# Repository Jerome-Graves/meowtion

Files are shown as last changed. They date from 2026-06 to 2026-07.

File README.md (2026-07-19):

<p align="center">
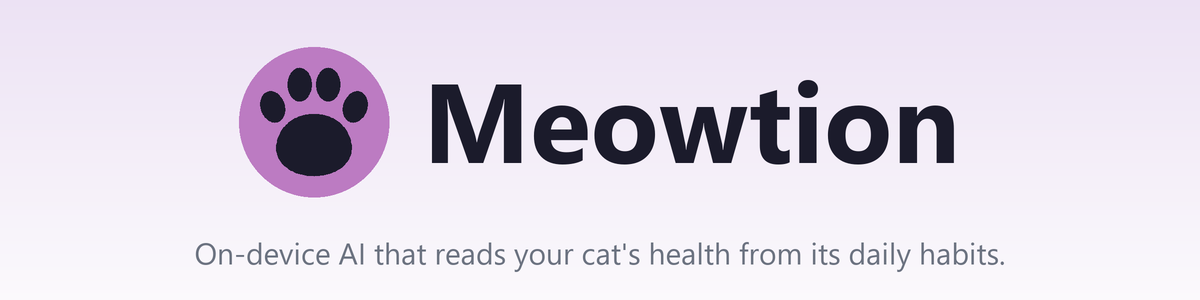
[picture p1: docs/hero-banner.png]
Meowtion — on-device AI that reads your cat's health from its daily habits
  
</p>

<p align="center">
  <a href="https://meowtion.streamlit.app"><b>🐾 Live dashboard</b></a>
  &nbsp;·&nbsp; <a href="#how-it-works">How it works</a>
  &nbsp;·&nbsp; <a href="#build-your-own">Build your own</a>
  &nbsp;·&nbsp; <a href="#license">License</a>
</p>

<p align="center">
  
</p>

<p align="center">
  
  
  
  
</p>

<p align="center">
  
  
  
  
  
  
</p>

---

**A smart cat collar that watches your cat's health through its habits.** On-device AI tracks
eating, drinking, activity, rest and purring, surfacing the routine changes that can flag illness
early (cats hide it well). It is trainable to recognise any behaviour, all on a live dashboard.

## The problem

Cats are experts at hiding illness, so by the time something looks obviously wrong it is often
already advanced. The early warning is in their routine: a cat that suddenly drinks more, eats
less, or stops grooming is telling you something. Meowtion watches those habits continuously, so
you notice the change rather than the crisis.

## How it works

A battery collar senses on the cat and classifies behaviour on the device itself. It relays the
result over Bluetooth to a plugged-in base station, which forwards it to the cloud over WiFi. A
hosted dashboard shows the owner their cat's activity and trends, live.

```text
  Cat
   │
   ▼
  Collar     nRF52840 Sense · Zephyr · on-device AI · battery
   │  BLE
   ▼
  Station    ESP32-S3 · ESP-IDF · Wi-Fi gateway · mains-powered
   │  Wi-Fi / HTTPS
   ▼
  Firebase   Auth · Realtime Database · Cloud Storage · Functions
   │
   ▼
  Dashboard  Streamlit + Firebase web
   │
   ▼
  Owner
```

The collar is Bluetooth-only, so the always-on station is its gateway to the cloud. It is
multi-user: each owner registers their own cats and stations and sees only their own data.

### On-device AI

The collar runs a confidence-gated cascade: a motion (IMU) model always runs, and when it is
unsure a short audio model confirms (eating and drinking look alike by motion, but not by sound).
Both are tiny int8 TensorFlow Lite Micro models. Classification happens on the collar, and raw
audio is processed on-device and discarded, never recorded or transmitted.

### Teach it any behaviour

The pipeline is not hard-coded to a fixed set of actions. You define the behaviours to recognise
in the dashboard (eat, drink, purr, scratch, litter-tray, and so on), label the captured clips,
and the model trains on whatever set you choose. Meowtion is a platform for recognising any pet
behaviour, not a fixed-function gadget.

## Repository

```
meowtion/
├── hardware/     the physical build: parts, 3D-print files, assembly   (hardware/README.md)
├── firmware/     on-device code: collar (nRF52840), station (ESP32-S3)
├── app/          the web app
│   ├── dashboard/  Streamlit + static front end                        (app/dashboard/README.md)
│   └── firebase/   Auth, database, storage, functions, rules           (app/firebase/README.md)
└── docs/         system documentation, incl. the full technical reference (docs/technical/)
```

**Full technical reference** (hardware, firmware, on-device AI, training, cloud, protocols,
security): [`docs/technical/`](docs/technical/) — read the prebuilt
[PDF](docs/technical/meowtion-technical.pdf) or build it from the LaTeX sources.

## Build your own

The hardware is open. Print the enclosure, solder the boards, flash both chips, and point them at
your own Firebase project.

1. **Hardware** (parts, prints, assembly): [`hardware/README.md`](hardware/README.md)
2. **Backend** (create the Firebase project and deploy): [`app/firebase/README.md`](app/firebase/README.md)
3. **Dashboard** (run or host the web app): [`app/dashboard/README.md`](app/dashboard/README.md)
4. **Firmware** (flash the collar and station): [`firmware/collar/README.md`](firmware/collar/README.md), [`firmware/station/README.md`](firmware/station/README.md)

## Tech stack

- **Collar:** Seeed XIAO nRF52840 Sense, Zephyr / nRF Connect SDK, TensorFlow Lite Micro
- **Station:** Seeed XIAO ESP32-S3, ESP-IDF, NimBLE + WiFi
- **Cloud:** Firebase (Auth, Realtime Database, Cloud Storage, Python Cloud Functions)
- **Dashboard:** Streamlit (Python) + Firebase web SDK (JavaScript)
- **Training:** TensorFlow, run server-side in a Cloud Function

## Privacy and security

Data is private per owner: the database and storage rules scope every read and write to the owning
account. Devices carry only a scoped, revocable token, never the owner's password. The microphone
is used only for on-device classification, so raw audio is never stored or transmitted. The
collar-to-station Bluetooth link is encrypted (LE Secure Connections), so a nearby device cannot
eavesdrop on it or push a model to the collar. The web API key is a public client identifier (safe to
ship); no service-account key is in the repo. See
[`app/firebase/README.md`](app/firebase/README.md) for the full model.

## Roadmap

Meowtion runs end to end today. What's next, roughly in priority order:

- **From activity to health insight** — adaptive per-cat baselines, multi-day trend anomaly detection,
  and a concise vet-shareable summary when a habit drifts. This is the core goal: notice the change
  early, and it needs no new hardware.
- **Richer, per-cat recognition** — more behaviours (scratching, litter-tray, grooming, play) and a
  short per-cat fine-tune, both straight out of the label-agnostic pipeline.
- **Longer battery life** — hardware wake-on-motion (an IMU interrupt waking the SoC from deep sleep)
  and tuning the activity gate and audio duty cycle against the measured power budget.
- **Multiple cats, shared stations** — model generalisation across cats, and telling apart two cats
  that share a bowl or station.
- **Full firmware over the air** — today only models are delivered wirelessly; extend the same
  mechanism to complete firmware updates.
- **Field validation and publication** — a larger, multi-household dataset (ideally with vet-confirmed
  events) and a write-up of the confidence-gated cascade.

## License

- **Code** (firmware, app, scripts): [MIT](LICENSE).
- **Hardware** (the designs and 3D-print files in [`hardware/`](hardware/)):
  [CERN-OHL-S v2](hardware/LICENSE), the strongly-reciprocal open-hardware licence.

Copyright (c) 2026 Jerome Graves and Rose Delcour-Min.

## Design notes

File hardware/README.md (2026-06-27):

# Hardware

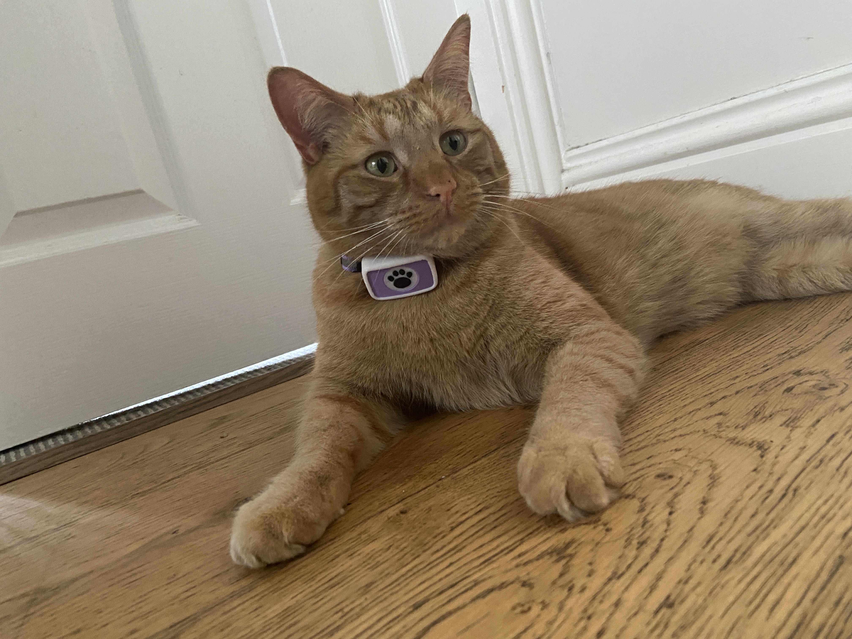
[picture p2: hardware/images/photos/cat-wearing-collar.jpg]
A cat wearing the Meowtion collar


Everything physical for the two devices: the parts you need and how to print, assemble
and power them. There's no custom PCB, each device is a Seeed XIAO board in a 3D-printed shell.

- 3D print files are in [`3d-files/`](3d-files/). The front shell is shared between the
  collar and the station; the rest is per-device.
- Once it's built, flashing and first-time setup are in [`../firmware/`](../firmware/) and
  [`../docs/`](../docs/).

## Parts

### Collar (one per cat, battery, worn on the cat)
| Part | Qty | Notes |
|---|-----|---|
| Seeed XIAO nRF52840 Sense | 1 | The brain. Onboard IMU + mic do all the sensing, no extra parts to wire. |
| 1S LiPo battery (3.7 V), 100 mAh, **with BMS/protection** | 1 | Powers the collar; solder to the BAT pads, mind polarity. Use a cell with a built-in protection circuit (BMS). |
| 20 mm hydrophobic PTFE filter membrane disc | 1 | Goes over the mic hole in the front shell: passes sound, keeps water and dust out. |
| 10 mm quick-release / safety collar | 1 | Any standard one; the silicone skin mounts to it. |

### Station (one per spot, mains powered, by the bowl)
| Part | Qty | Notes |
|---|-----|---|
| Seeed XIAO ESP32-S3 | 1 | BLE + WiFi gateway: hears the collar, uploads to the cloud. |
| USB-C cable + 5 V supply | 1 | Mains powered, no battery. |

### Tools / consumables
| Item | Notes |
|---|---|
| USB-C cable | Flash + set up both boards. |
| Filament | PETG (rigid shells), flexible TPU (collar skin). |
| Water-resistant glue | Bonds the shell halves and seals the assembly against splashes. |
| FDM 3D printer | A standard 0.4 mm nozzle is fine. |

## Print
| File | Used by | Filament |
|---|---|---|
| `front-shell.stl` | collar + station | PETG |
| `collar-back-shell.stl` | collar | PETG |
| `collar-silicone-skin.stl` | collar | flexible TPU |
| `station-back-shell.stl` | station | any rigid |

## Assemble

Both devices, exploded , the boards drop into the back shells and the front covers clip on:

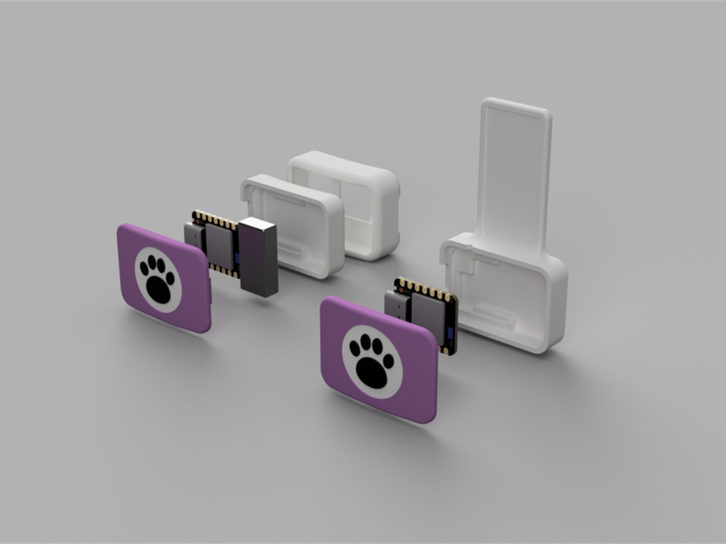
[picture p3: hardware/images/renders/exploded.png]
Collar and station, exploded view


### Collar
1. Seat the XIAO nRF52840 Sense + LiPo in the back shell.
2. Fit the 20 mm PTFE membrane over the mic hole on the inside of the front shell.
3. Close the front and back shells and bond them with water-resistant glue.
4. Slip the sealed assembly into the TPU skin and attach it to the quick-release collar.

| PTFE membrane over the mic hole | Boards seated in their shells |
|---|---|
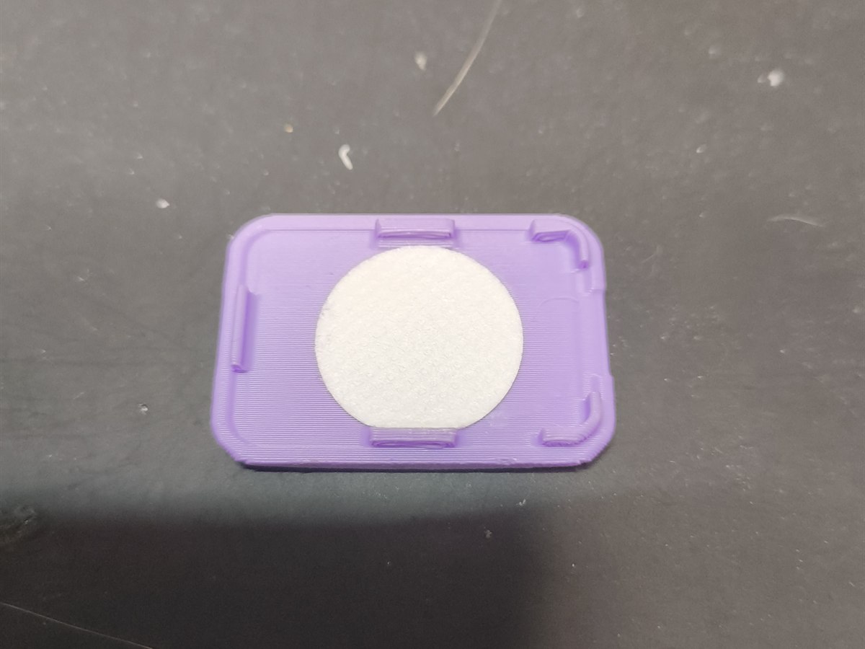
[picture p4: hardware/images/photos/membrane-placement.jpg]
PTFE membrane in the front shell
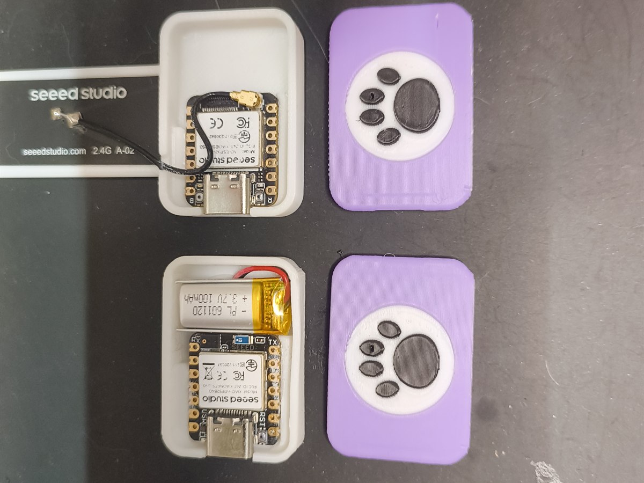
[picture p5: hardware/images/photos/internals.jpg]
Inside the collar and station
|  |  |

### Station
1. Seat the XIAO ESP32-S3 in the shell.
2. Glue it closed with water-resistant glue.
3. Plug into USB power by the bowl.

## Finished collar

| Front | Back |
|---|---|
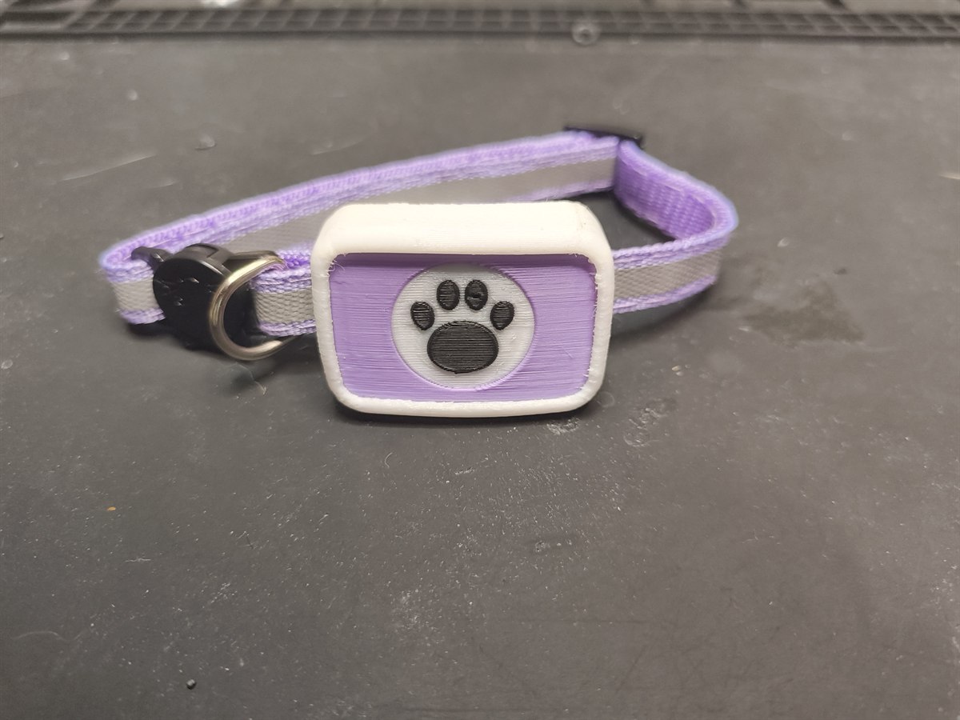
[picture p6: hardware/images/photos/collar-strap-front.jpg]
Completed collar on strap, front
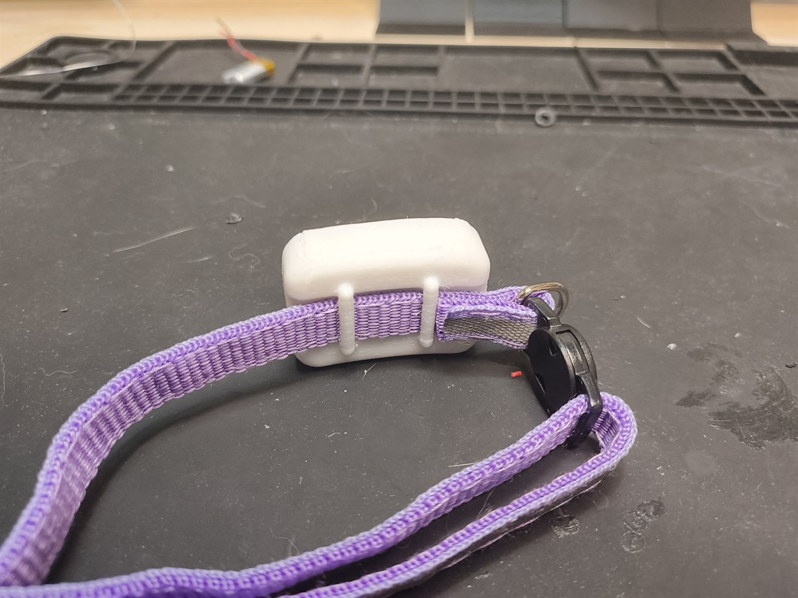
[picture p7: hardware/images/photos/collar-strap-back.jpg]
Completed collar on strap, back
|  |  |

## Next
Flash both boards and register them, see [`../firmware/`](../firmware/) and [`../docs/`](../docs/).

## License
The hardware designs and 3D-print files in this directory are licensed under
[CERN-OHL-S v2](LICENSE) (strongly reciprocal). The repository's code is [MIT](../LICENSE).
Copyright (c) 2026 Jerome Graves and Rose Delcour-Min.

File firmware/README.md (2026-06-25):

# Firmware

Two devices that share one BLE wire format.

| Dir | Device | Stack | Role |
|-----|---|---|---|
| [`collar/`](collar/README.md) | Seeed XIAO nRF52840 Sense | Zephyr / nRF Connect SDK | On the cat. BLE-only: senses, advertises telemetry, and streams paired audio + IMU clips for training. |
| [`station/`](station/README.md) | Seeed XIAO ESP32-S3 | ESP-IDF | By the bowl. BLE central + WiFi gateway: relays the collar to Firebase and uploads training clips. |
| [`common/`](common/) | shared | C header | `meow_protocol.h`: the BLE clip-frame wire format + µ-law codec, included by both so the format can't drift. |

## How they fit together

```
collar  --BLE-->  station  --HTTPS-->  Firebase  -->  dashboard
```

The collar is Bluetooth-only and battery-powered, so the always-on, mains-powered station is its
gateway to the cloud. In **training** mode the collar streams audio + IMU clips and the station
uploads them; in **production** mode the collar classifies on-device and the station relays only
the result. System overview: the root [README](../README.md).

## Build

- **Collar** (Zephyr): `./build.ps1` , wraps `west` / the NCS toolchain. See [collar/README.md](collar/README.md).
- **Station** (ESP-IDF): `idf.py build`. See [station/README.md](station/README.md).

Both are verified building (collar on NCS v3.3.1; station on ESP-IDF).

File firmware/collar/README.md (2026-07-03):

# Collar firmware (nRF52840, Zephyr)

The cat collar. **BLE-only** , it senses on the cat and runs one **connectable** advertisement
carrying an 8-byte telemetry packet plus a custom audio service. When the station connects and
subscribes, the collar streams paired audio + IMU in 100 ms frames for training capture. It never
touches WiFi/internet, which keeps it tiny and low-power, and it always runs on its own battery.

## Modules (`src/`)

| File | Responsibility |
|---|---|
| `main.c` | boot + the telemetry loop (orchestration only) |
| `ble.c` | advertising, identity, the audio GATT service, notify |
| `audio.c` | PDM mic capture -> 8 kHz µ-law |
| `streaming.c` | the decoupled reader/sender threads that assemble + send frames |
| `battery.c` | 1S LiPo charge via the onboard divider |
| `imu.c` | LSM6DS3TR-C continuous sampler |
| `activity.c` | rules-based activity gate (cascade tier 0: low-power rest / wake) |
| `production.c` | rolling IMU window: runs inference and writes real telemetry |
| `classifier.c` | the confidence-gated action cascade (IMU first, audio confirms when unsure) |
| `tflm_classifier.cpp` | TensorFlow Lite Micro backend for the cascade (runtime-loaded models) |
| `model_loader.h` | runtime model-install API (`clf_set_imu_model` / `clf_set_audio_model`) |
| `ota.c` | OTA receive state machine: stages models to flash, defers the swap |
| `audio_codec.h` | µ-law + the model-input audio representation |

## Telemetry packet (manufacturer AD data, 8 bytes)

| bytes | field |
|---|---|
| 0-1 | company id (`0xFFFF`, test) |
| 2 | version |
| 3 | state (0 sleep, 1 rest, 2 active, 3 walk, 4 play, 5 groom) |
| 4 | activity (0-100) |
| 5-6 | steps (uint16, little-endian) |
| 7 | battery (0-100) |

The collar's BLE address identifies which collar it is, so no id goes in the payload.

## On-device AI

The inference engine is **TensorFlow Lite Micro** (`tflm_classifier.cpp`). It runs a
confidence-gated cascade: the IMU model classifies first, and the audio model confirms only when the
IMU is unsure. No model is compiled into the firmware , each stage loads its `.tflite` at **runtime**
(`clf_set_imu_model` / `clf_set_audio_model`, the future OTA path). Until a model lands the engine
runs **model-free**: `clf_*_model_present()` is false and the cascade returns `UNKNOWN`, so the
firmware is safe to run with no model at all. The input pre-processing (per-window normalization,
int8 quantization from the model's own scale/zero-point) mirrors the training pipeline so on-device
inference matches what was trained.

Two things still pending: the telemetry state/activity/steps are **simulated** for now (a dwell-based
behaviour state machine; real battery is wired) and switch to real classifier output once a model is
loaded; and the OTA delivery that pushes a trained `.tflite` to the collar is **Phase 3**. See the
root [README](../../README.md) for the model + OTA plan. The cascade itself already runs at capture
time in `streaming.c` on the IMU window paired with each clip.

## Build & flash

```
./build.ps1
```

`build.ps1` finds the local NCS toolchain itself, runs `west build -b xiao_ble/nrf52840/sense`, and copies the
UF2. The XIAO nRF52840 has **no debug COM port** for flashing , flashing is always **UF2
drive-copy**: double-tap RESET so the board mounts as a USB drive, then re-run (the script copies
the UF2 across). Artifact: `build/collar/zephyr/zephyr.uf2`. Verified with **NCS v3.3.1**.

Console note: the firmware uses the **legacy** USB device stack (`CONFIG_USB_DEVICE_STACK` +
`CONFIG_USB_CDC_ACM`) and calls `usb_enable()`, because the new (NEXT) stack's CDC console silently
drops output on this board. Keep exactly one `zephyr,cdc-acm-uart` node.

## Watching it run

Open the CDC serial port (any baud) , `MEOW> collar id=cat_xxxxxx` and `state= steps= batt=` print
every 2 s. The port only appears once the app is running (not in the UF2 bootloader). That
`MEOW> collar id=` line is what the dashboard reads over Web Serial to register the collar.

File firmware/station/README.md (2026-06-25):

# Station firmware (ESP32-S3, ESP-IDF)

The base station. A **BLE central** that hears registered collars and a **WiFi gateway** that
relays them to the owner's Firebase account. It also captures short audio + IMU clips for training
and uploads them through the authenticated `upload_clip` Cloud Function.

No Firebase login: WiFi + owner + a per-device **token** are provisioned over USB serial and stored
in NVS. The database rules authorise the device because the token is registered to that owner
(`deviceTokens/<token>/owner`); delete the token to revoke.

## Modules (`main/`)

| File | Responsibility |
|---|---|
| `main.c` | boot + the ~1 s orchestration loop |
| `config.c` | provisioned creds, NVS, USB-serial provisioning |
| `board.c` | power source (USB vs battery) |
| `wifi.c` | STA bring-up + time sync |
| `cloud.c` | the Firebase RTDB / HTTP layer (the only HTTP) |
| `weather.c` | Open-Meteo feed |
| `ble.c` | the whole NimBLE collar subsystem (scan/relay + audio capture), behind `ble_service()` |
| `ota.c` | OTA model delivery: pushes trained `.tflite` models to the collar over BLE |

## Clip upload

Captured clips are POSTed to the `upload_clip` Cloud Function with the device token; the function
verifies the token's owner and writes the file to that owner's Storage area (clients cannot write
Storage directly). The station records the returned Storage path under `/clips`. See
[`../../app/firebase/README.md`](../../app/firebase/README.md).

## OTA model delivery

The station also delivers trained models to the collar over BLE (Phase 3 of the model pipeline).
The shared wire protocol is fixed in [`../common/meow_ota.h`](../common/meow_ota.h): the collar is the
GATT server that stages a `.tflite` into flash, the station is the client that pushes it.

- **Version gate.** The `train` Cloud Function bumps `users/<uid>/models/version` and mirrors it into
  this station's own config as `modelVer` (the station can read only its own
  `users/<uid>/devices/<token>/` subtree, not `users/<uid>/models`). The station reads `config/modelVer`,
  keeps its own last-pushed version in NVS, and a push is due when the config version is higher.
- **Download.** For each slot it GETs the model from Storage at the public-read path
  `models/<uid>/imu_model.tflite` (IMU slot) and `models/<uid>/audio_model.tflite` (audio slot). A 404
  just means that slot has no model yet and is skipped.
- **Push.** It computes a CRC-32/IEEE over the bytes (matching the collar's `crc32_ieee`), then over a
  brief dedicated BLE connection writes `BEGIN`, streams the model to the DATA characteristic in
  `(MTU-3)` write-with-response chunks (the collar's flash-write flow control), and writes `END`. On
  the collar's `OK` it records the new version in NVS; on any error it leaves NVS unchanged and retries.

A push runs only when a registered collar is in range and audio capture is idle, so it never contends
with the capture/relay path for the radio.

## Build & flash

```
. $env:USERPROFILE\esp\esp-idf\export.ps1
idf.py build
idf.py -p <COM> flash monitor
```

(The repo's VS Code task **Build+Flash Station** wraps this.) Verified building with ESP-IDF.

## Provisioning

Send a JSON line over USB serial (the dashboard's "Connect a device" form does this automatically):

```
{"ssid":"..","pass":"..","owner":"<uid>","token":"<random>","name":"..","lat":50.8,"lon":-0.1}
```

Re-provision any time from the dashboard, or wipe with `idf.py erase-flash`.

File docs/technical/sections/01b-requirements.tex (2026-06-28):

\section{Requirements and design constraints}
\label{sec:requirements}

This section states the requirements the system meets and the constraints that shaped it, so the
chapters that follow read as the response to them. The final column of each table points to the
section where the requirement is addressed.

\subsection{Functional requirements}

\Cref{tab:fr} lists what the system must do for an owner.

\begin{table}[ht]
  \centering
  \caption{Functional requirements.}
  \label{tab:fr}
  \begin{tabularx}{\textwidth}{@{}l X l@{}}
    \toprule
    \textbf{ID} & \textbf{Requirement} & \textbf{Addressed in} \\
    \midrule
    FR-1 & Recognise a cat's everyday behaviours (eating, drinking, activity, rest, grooming) from a
           collar-worn sensor. & \cref{sec:on-device-ai} \\
    FR-2 & Perform classification on the wearable itself, in real time, without streaming raw sensor
           data off the cat. & \cref{sec:on-device-ai} \\
    FR-3 & Let the owner define the behaviour set; do not hard-code it in firmware. &
           \cref{sec:training-pipeline} \\
    FR-4 & Provide a closed training loop (capture, label, train, deploy) driven entirely from the
           dashboard, with no local toolchain. & \cref{sec:training-pipeline} \\
    FR-5 & Deliver trained models to the collar over the air, with no firmware reflash. &
           \cref{sec:firmware-station,sec:protocols} \\
    FR-6 & Present the owner a live view and a longitudinal history with health-oriented analytics. &
           \cref{sec:dashboard} \\
    FR-7 & Support multiple owners, each seeing only their own cats and devices. &
           \cref{sec:cloud-backend} \\
    FR-8 & Offer a public, read-only way to explore the product without an account. &
           \cref{sec:dashboard} \\
    \bottomrule
  \end{tabularx}
\end{table}

\subsection{Non-functional requirements}

\Cref{tab:nfr} lists the quality attributes and limits the design must meet, the constraints behind
many of the engineering choices that follow.

\begin{table}[ht]
  \centering
  \caption{Non-functional requirements and quality attributes.}
  \label{tab:nfr}
  \begin{tabularx}{\textwidth}{@{}l X l@{}}
    \toprule
    \textbf{ID} & \textbf{Requirement} & \textbf{Addressed in} \\
    \midrule
    NFR-1 & \textbf{Power.} The collar must run for a useful time on a collar-sized cell, which
            precludes Wi-Fi on the wearable, bounds the duty cycle of the audio path, and is met
            chiefly by the rules-based activity gate that rests the collar between bouts of motion. &
            \cref{sec:hardware,sec:on-device-ai,sec:firmware-collar} \\
    NFR-2 & \textbf{Footprint.} Inference must fit the microcontroller's RAM alongside the BLE stack. &
            \cref{sec:on-device-ai} \\
    NFR-3 & \textbf{Privacy.} Raw audio must never leave the collar in normal operation; data must be
            scoped per owner. & \cref{sec:security-privacy} \\
    NFR-4 & \textbf{Credential safety.} Battery devices must not hold the owner's password; device
            authorisation must be revocable. & \cref{sec:security-privacy} \\
    NFR-5 & \textbf{Reproducibility.} A third party must be able to build and run the system from the
            repository without contacting the authors. & \cref{sec:cloud-backend} \\
    NFR-6 & \textbf{Openness.} Hardware designs and code are released under open licences. &
            \cref{sec:hardware} \\
    \bottomrule
  \end{tabularx}
\end{table}

\subsection{Constraints}

\begin{description}[leftmargin=1.6em,style=nextline]
  \item[Radio.] The collar is Bluetooth Low Energy only; BLE is low-power but short-range and is not
        an internet transport, so a mains-powered station is required as the gateway
        (\cref{sec:architecture}).
  \item[Compute.] On-device inference runs on a Cortex-M4F with a few hundred kilobytes of RAM and no
        operating-system heap budget to spare, so models are int8 and arenas are statically sized
        (\cref{sec:on-device-ai}).
  \item[Connectivity.] The station is provisioned with credentials but never logs in as a user; it
        authenticates to the cloud with a single revocable token (\cref{sec:firmware-station}).
  \item[Hosting.] The dashboard is hosted on a managed Python platform (Streamlit Community Cloud),
        which does not expose server-side cookies, shaping how the session is read
        (\cref{sec:dashboard}).
\end{description}

\Cref{sec:evaluation} revisits these requirements and constraints and reports the extent to which
each is currently met.

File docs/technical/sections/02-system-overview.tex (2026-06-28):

\section{System architecture and data flow}
\label{sec:architecture}

This section is the map for the rest of the document. It introduces the four tiers and their
responsibilities, the two operating modes, and the four end-to-end data flows that together cover
everything the system does: live monitoring, training capture, device onboarding, and model delivery.

\subsection{Topology}

Meowtion is a four-tier system, \cref{fig:architecture}: the \textbf{collar} on the cat, the
\textbf{station} in the home, the \textbf{cloud} backend, and the owner's \textbf{dashboard}. The
defining constraint is that the collar is BLE-only and battery-powered, with no route to the internet
of its own. The mains-powered station bridges that gap, giving the collar a cheap, always-on
Bluetooth peer and a Wi-Fi path to the cloud. Everything above the collar is conventional web
infrastructure; everything at the collar is shaped by power and radio budget.

\begin{figure}[ht]
  \centering
  \resizebox{\textwidth}{!}{%
  \begin{tikzpicture}[node distance=9mm and 13mm]
    \node[mwnode] (cat) {Cat};
    \node[mwnode, right=of cat, fill=mwlav!12, draw=mwlav] (collar)
      {\textbf{Collar}\\\footnotesize XIAO nRF52840 Sense\\\footnotesize Zephyr\,/\,NCS, battery\\\footnotesize sensing + on-device AI};
    \node[mwnode, right=of collar, fill=mwlav!12, draw=mwlav] (station)
      {\textbf{Station}\\\footnotesize XIAO ESP32-S3\\\footnotesize ESP-IDF, mains\\\footnotesize BLE central + Wi-Fi gateway};
    \node[mwnode, right=of station] (cloud)
      {\textbf{Firebase}\\\footnotesize Auth, Realtime DB\\\footnotesize Storage, Functions};
    \node[mwnode, below=15mm of station] (dash)
      {\textbf{Dashboard}\\\footnotesize Streamlit + web SDK};
    \node[mwnode, left=of dash] (owner) {Owner};

    \draw[mwedge] (cat) -- node[above,font=\scriptsize,text=mwmut]{sensing} (collar);
    \draw[mwbiedge] (collar) -- node[above,font=\scriptsize,text=mwmut]{BLE} (station);
    \draw[mwbiedge] (station) -- node[above,font=\scriptsize,text=mwmut]{Wi-Fi\,/\,HTTPS} (cloud);
    \draw[mwedge] (cloud.south) |- (dash.east);
    \draw[mwedge] (dash) -- (owner);
  \end{tikzpicture}%
  }
  \caption{End-to-end topology. The collar is BLE-only, so the always-on station is its gateway to
           the cloud. The dashboard is a separate client of the same backend.}
  \label{fig:architecture}
\end{figure}

\subsection{Component responsibilities}

\Cref{tab:responsibilities} summarises what each tier is responsible for.

\begin{center}
  \captionof{table}{What each tier is responsible for.}
  \label{tab:responsibilities}
  \begin{tabularx}{\textwidth}{@{}lX@{}}
    \toprule
    \textbf{Tier} & \textbf{Responsibility} \\
    \midrule
    Collar    & Sense (IMU + microphone), classify behaviour on-device, advertise the result as BLE
                telemetry, and, when a station subscribes, stream paired audio\,+\,IMU clips for
                training and accept models over the air. Holds no credentials. \\
    Station   & Scan for and relay registered collars to the cloud; capture and upload training
                clips; fetch trained models from Storage and push them to the collar over BLE.
                Authenticates to the cloud with a per-device token, not a login. \\
    Cloud     & Firebase: authenticate owners, store the live data and history (Realtime Database),
                store training clips and trained models (Storage), and run server-side logic (Cloud
                Functions for training and authenticated clip upload). Enforces per-owner isolation. \\
    Dashboard & The owner-facing web app: a live current-state view and longitudinal health
                analytics, plus a static front door for sign-in and device registration and a
                dev console for data capture and training. \\
    \bottomrule
  \end{tabularx}
\end{center}

\subsection{Operating modes}

A station runs in one of two modes at a time, selected per station from the dashboard. The mode
governs what crosses the BLE link and what the station does with it.

\begin{description}[leftmargin=1.6em,style=nextline]
  \item[Production mode] The everyday monitoring mode and privacy-preserving default. The collar
        classifies on-device and advertises only the result; the station reads it and relays it to
        the cloud. No audio or raw motion leaves the collar.
  \item[Training mode] The data-collection mode for teaching a new behaviour. While a registered
        collar is in range, the station subscribes to the collar's audio service; the collar streams
        paired audio\,+\,IMU clips, which the station slices and uploads and the owner labels and
        trims in the dev console. It is used deliberately and temporarily, not continuously.
\end{description}

\subsection{End-to-end data flows}

Four flows fully describe the system's behaviour. Each is given below as a concrete sequence of steps
across the tiers; the wire formats are specified in \cref{sec:protocols} and the security rules in
\cref{sec:security-privacy}.

\paragraph{Flow 1 --- Live monitoring (production).}
The steady state of a deployed system.
\begin{enumerate}[leftmargin=1.6em,itemsep=2pt]
  \item The collar samples its IMU continuously and runs the on-device cascade
        (\cref{sec:on-device-ai}); when the motion result is ambiguous it briefly samples the
        microphone and runs the audio model to confirm.
  \item The collar encodes the outcome (class index, confidence, step count, battery) into an 8-byte
        BLE telemetry advertisement (\cref{sec:protocols}). Its BLE address identifies the collar, so
        the payload carries no identifier.
  \item The station, scanning continuously, hears the advertisement from a \emph{registered} collar,
        timestamps it, maps the class index to the owner's label set, and writes the current state
        plus an event record to the Realtime Database over authenticated HTTPS.
  \item The dashboard, reading the same database, refreshes the live card within seconds and folds
        the new event into the history and health analytics (\cref{sec:dashboard}).
\end{enumerate}

\begin{figure}[ht]\centering
  \resizebox{\textwidth}{!}{%
  \begin{tikzpicture}[node distance=18mm, every node/.style={font=\footnotesize}]
    \node[mwnode] (collar) {Collar\\\scriptsize classify on-device};
    \node[mwnode, right=of collar] (station) {Station\\\scriptsize map class\,$\to$\,label};
    \node[mwnode, fill=mwlav!8, right=of station] (rtdb) {Realtime DB\\\scriptsize current + events};
    \node[mwnode, right=of rtdb] (dash) {Dashboard\\\scriptsize live + history};
    \draw[mwedge] (collar) -- node[above,text=mwmut,font=\scriptsize]{telemetry AD (BLE)} (station);
    \draw[mwedge] (station) -- node[above,text=mwmut,font=\scriptsize]{HTTPS (token)} (rtdb);
    \draw[mwedge] (rtdb) -- node[above,text=mwmut,font=\scriptsize]{read} (dash);
  \end{tikzpicture}}
  \caption{Flow~1, live monitoring. The collar advertises an 8-byte telemetry packet; the station
           maps the class index to a label and writes the live state and events to the database, which
           the dashboard reads.}
  \label{fig:live-flow}
\end{figure}

\paragraph{Flow 2 --- Training capture.}
How labelled data is collected to teach a behaviour.
\begin{enumerate}[leftmargin=1.6em,itemsep=2pt]
  \item In the dev console the owner puts a station into training mode and selects the action being
        recorded (the ``live label'').
  \item The station connects to the in-range collar and subscribes to its audio characteristic. The
        collar streams continuously in 100\,ms frames, each a header followed by an audio payload and
        a time-aligned IMU payload (\cref{sec:protocols}).
  \item The station concatenates frames, slices them into fixed-length clips, and POSTs each clip's
        bytes to the \texttt{upload\_clip} Cloud Function with its device token. The function
        verifies the token's owner and writes the clip to that owner's Storage area; the station
        records the clip's metadata (label, paths, IMU presence) in the database.
  \item The owner reviews clips in the dev console: trims the waveform, confirms or changes the label,
        and discards bad takes. The labelled clips are the training set for Flow~4.
\end{enumerate}

\paragraph{Flow 3 --- Device onboarding.}
How a station and collar are registered to an owner, performed once per device.
\begin{enumerate}[leftmargin=1.6em,itemsep=2pt]
  \item The owner signs in on the static front door and connects the station over USB using the
        browser's Web Serial API. The page mints a random per-device \emph{token}, records it under
        the owner's account (\texttt{deviceTokens/<token>/owner}) and as a station device entry, and
        hands the station its Wi-Fi credentials, the owner id, and the token over the serial link.
        The station stores these in non-volatile storage; the token is its sole credential.
  \item The station comes online, syncs time, and begins scanning, publishing any unregistered
        collars it hears to its \texttt{seen} list.
  \item The owner registers a heard collar with one tap in the dashboard. The collar then appears as a
        device on the account and is relayed by the station. Deleting the token revokes the device.
\end{enumerate}

\begin{figure}[ht]\centering
  \begin{tikzpicture}[node distance=9mm, every node/.style={font=\footnotesize}]
    \node[mwterm] (a) {Owner signs in};
    \node[mwflow, below=of a, text width=7.2cm, align=left] (b)
      {Connect the station over USB (Web Serial). The dashboard mints a random token, records
       \texttt{deviceTokens/\allowbreak <token>/owner} and a station device entry};
    \node[mwflow, below=of b, text width=7.2cm, align=left] (c)
      {Provision the station over USB: Wi-Fi credentials, the owner id, and the token (stored in NVS)};
    \node[mwflow, below=of c, text width=7.2cm, align=left] (d)
      {Station comes online, syncs time, scans, and publishes unregistered collars it hears (\texttt{seen})};
    \node[mwterm, below=of d] (e) {Owner registers a heard collar (one tap)};
    \draw[mwedge] (a) -- (b); \draw[mwedge] (b) -- (c); \draw[mwedge] (c) -- (d); \draw[mwedge] (d) -- (e);
  \end{tikzpicture}
  \caption{Flow~3, connecting devices. A station is paired over USB and provisioned with a scoped
           token; once online it surfaces nearby collars, which the owner registers with one tap.}
  \label{fig:onboarding}
\end{figure}

\paragraph{Flow 4 --- Model training and over-the-air delivery.}
How labelled clips become a model running on the collar.
\begin{enumerate}[leftmargin=1.6em,itemsep=2pt]
  \item The owner triggers training from the dev console. The \texttt{train} Cloud Function reads the
        account's labelled clips, derives the class set from the labels present, trains an int8 IMU
        model and an int8 audio model, uploads them to Storage under \texttt{models/<uid>/}, and bumps
        the account's model version (\cref{sec:training-pipeline}).
  \item The station learns a new version is available (mirrored into its own device config), downloads
        each model from Storage, and, over a brief dedicated BLE connection, streams it to the collar
        with a CRC-checked begin/data/end protocol (\cref{sec:protocols}).
  \item The collar stages the model into its dedicated flash partition, verifies the CRC, loads it,
        and switches from advertising simulated state to advertising real classifier output. The path
        requires no firmware reflash.
\end{enumerate}

\subsection{Multi-tenant data model}

Meowtion is multi-tenant. Each owner creates an account and registers their own station(s) and
collar(s); all of an owner's data lives under \texttt{users/<uid>/} in the Realtime Database, and the
database and storage rules scope every read and write to the owning account
(\cref{sec:cloud-backend,sec:security-privacy}). The backend enforces isolation, not the client.
Battery devices never hold a login: a station authenticates with its scoped, revocable token, and a
collar holds nothing at all (the station relays it). A single public, read-only demo account,
designated in server-side config, lets anyone explore a populated dashboard without signing up.

\subsection{Technology summary}

\Cref{tab:stack} lists the technology used at each tier.

\begin{center}
  \captionof{table}{Technology at each tier.}
  \label{tab:stack}
  \begin{tabularx}{\textwidth}{@{}lX@{}}
    \toprule
    \textbf{Tier} & \textbf{Stack} \\
    \midrule
    Collar    & Seeed XIAO nRF52840 Sense; Zephyr / nRF Connect SDK (v3.3.1); TensorFlow Lite Micro
                with CMSIS-NN kernels \\
    Station   & Seeed XIAO ESP32-S3; ESP-IDF; NimBLE (BLE central) + Wi-Fi station \\
    Cloud     & Firebase: Authentication, Realtime Database, Cloud Storage, Python Cloud Functions
                (2nd gen) \\
    Dashboard & Streamlit (Python) + Firebase web SDK (JavaScript); hosted on Streamlit Community
                Cloud \\
    Training  & TensorFlow / Keras, executed server-side in a Cloud Function; int8 post-training
                quantisation to TensorFlow Lite \\
    \bottomrule
  \end{tabularx}
\end{center}

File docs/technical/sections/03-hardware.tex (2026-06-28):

\section{Hardware}
\label{sec:hardware}

The build is two devices: the collar worn by the cat and the station plugged in at home. There is no
custom PCB. Each device is a Seeed Studio XIAO module in a 3D-printed shell, chosen for the small
footprint, integrated radios, hand-solderable castellated pads, and, on the collar, on-module
sensors. The full parts list is in \cref{sec:appendix-bom}; print files and assembly steps are in
\texttt{hardware/README.md}. This section summarises the design and its reasoning.

\subsection{Collar}

The collar is built around the Seeed XIAO nRF52840 Sense. The nRF52840 provides a Bluetooth Low
Energy radio and enough flash and RAM to run quantised neural-network inference on its Cortex-M4F.
Critically for Meowtion, the \emph{Sense} variant carries both sensors the system needs on the module
itself, a six-axis IMU (LSM6DS3TR-C) and a PDM MEMS microphone, so the collar needs no external
sensor breakout and stays small and light.

The collar runs on its own 1S LiPo cell (3.7\,V, 100\,mAh, with a built-in protection circuit)
soldered to the XIAO's BAT pads and charged through the module's onboard divider. The build is
completed by a 20\,mm hydrophobic PTFE filter membrane over the mic hole, PETG front and back shells,
a flexible TPU skin, and a 10\,mm quick-release safety strap. The full parts list is in
\cref{sec:appendix-bom}.

The IMU supplies the motion stream that is always classified; the microphone supplies the short audio
window used to disambiguate behaviours that look alike by motion but differ by sound
(\cref{sec:on-device-ai}). The microphone port sits behind the PTFE membrane in the front shell;
correct membrane placement matters for audio quality and water resistance and is documented in the
hardware guide.

\begin{figure}[ht]
  \centering
  \begin{subfigure}{0.31\textwidth}
    \centering
    
    \caption{Exploded view.}
    \label{fig:exploded}
  \end{subfigure}\hfill
  \begin{subfigure}{0.31\textwidth}
    \centering
    
    \caption{Assembled internals.}
    \label{fig:internals}
  \end{subfigure}\hfill
  \begin{subfigure}{0.31\textwidth}
    \centering
    
    \caption{PTFE membrane over the mic hole.}
    \label{fig:membrane}
  \end{subfigure}
  \caption{Collar and station hardware. Full parts, print files, and assembly steps are in
           \texttt{hardware/README.md}.}
  \label{fig:collar-hw}
\end{figure}

\subsection{Station}

The station is a Seeed XIAO ESP32-S3. The ESP32-S3 has both Wi-Fi and BLE, so a single module acts as
the BLE central that listens to the collar and the Wi-Fi client that reaches the cloud. Mains-powered
over USB-C, it scans and stays online continuously without the wearable's power constraints. It
carries no sensors of its own; its job is to hear the collar, capture training clips when asked, relay
results to the cloud, and push models to the collar. Its parts are listed in \cref{sec:appendix-bom}.

\subsection{Enclosure and assembly}

The front shell is shared between the collar and the station; the back shells and the collar's
flexible TPU skin are per-device. The collar shells are PETG for rigidity; the station back shell is
any rigid filament. The collar is assembled by seating the board and cell in the back shell, fitting
the PTFE membrane over the mic hole, bonding the shell halves with water-resistant glue, and slipping
the sealed unit into the TPU skin on a quick-release strap. The station is seated, glued closed, and
plugged in by the bowl. The hardware designs are released under CERN-OHL-S v2 (strongly reciprocal
open hardware).

\begin{figure}[ht]
  \centering
  \begin{subfigure}{0.40\textwidth}
    \centering
    \caption{Front, on the strap.}
    \label{fig:collar-front}
  \end{subfigure}\hfill
  \begin{subfigure}{0.40\textwidth}
    \centering
    \caption{Back, on the strap.}
    \label{fig:collar-back}
  \end{subfigure}
  \caption{The finished collar on a quick-release strap.}
  \label{fig:finished-collar}
\end{figure}

\subsection{Rationale for the split}

The collar must be small, light, and run for a useful time on a small cell, which rules out Wi-Fi on
the wearable: its power draw is incompatible with a collar-sized battery. BLE is low-power but
short-range and is not an internet transport. The fixed, mains-powered station resolves both
problems, giving the collar a cheap always-on BLE peer and a Wi-Fi path to the cloud. The split also
keeps the privacy boundary clean: the heavy and sensitive processing (including all audio) stays on
the collar, and only a classification result crosses to the station.

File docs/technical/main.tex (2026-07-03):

% =====================================================================
%  Meowtion Technical Documentation - master file.
%
%  Build with build.ps1 (XeLaTeX + Biber, no Perl/latexmk). See README.md.
%  Structure:
%    preamble/    packages, styling, document metadata
%    frontmatter/ title page
%    sections/    one .tex file per chapter, numbered for ordering
%    references.bib
% =====================================================================
\documentclass[11pt,a4paper]{article}

\input{preamble/metadata}
\input{preamble/packages}
\input{preamble/style}

% Resolve figures by filename: this folder, docs/, and the hardware image trees.
\graphicspath{{./}{../}{../../hardware/images/photos/}{../../hardware/images/renders/}}

\begin{document}

\input{frontmatter/titlepage}
\input{frontmatter/acknowledgements}

\tableofcontents
\clearpage
\listoffigures
\listoftables
\clearpage

% Glossary up front, so a reader can look up a term before meeting it.
\input{sections/15-glossary}

\clearpage
\part{Overview}
\input{sections/01-introduction}
\input{sections/01b-requirements}
\input{sections/02-system-overview}

\clearpage
\part{The device}
\input{sections/03-hardware}
\input{sections/04-firmware-collar}
\input{sections/05-firmware-station}

\clearpage
\part{On-device intelligence}
\input{sections/06-on-device-ai}
\input{sections/07-training-pipeline}

\clearpage
\part{Cloud and application}
\input{sections/08-cloud-backend}
\input{sections/09-dashboard}
\input{sections/09b-ui-walkthrough}

\clearpage
\part{Interfaces and security}
\input{sections/10-protocols}
\input{sections/11-security-privacy}

\clearpage
\part{Validation and roadmap}
\input{sections/11b-evaluation}
\input{sections/12-future-work}

\appendix
\input{sections/13-appendix-bom}
\input{sections/14-appendix-schema}
\input{sections/16-appendix-tests}

\printbibliography[heading=bibnumbered]

\end{document}

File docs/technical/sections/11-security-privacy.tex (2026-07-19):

\section{Security and privacy}
\label{sec:security-privacy}

Privacy is a design property of Meowtion, not a setting bolted on afterwards. The strongest guarantees
come from where work happens (on the collar) and how data is scoped (per owner, by enforced rules).

\subsection{On-device audio}

The microphone is used only for on-device classification. Audio is processed on the collar and
discarded; it is never written to flash in normal operation and never transmitted in production mode.
The collar's uplink is a classification result (a class index and a confidence), not a sensor stream.
The one exception is deliberate and owner-driven: in training mode the owner chooses to capture clips
to teach a behaviour, and those clips are stored privately to their own account and are never
world-readable, even for the public demo.

\subsection{Per-owner isolation}

All of an owner's data lives under \texttt{users/<uid>/}, and the database and storage rules scope
every read and write to the owning account, so owners (and their token-authenticated devices) touch
only their own data. Isolation is enforced by the backend, not the client. The Storage rules go
further and deny \emph{all} direct client writes: training clips are written only by the
\texttt{upload\_clip} function and are readable only by their owning account, and model blobs are
public-read (so the token-only station can fetch one) but writable only by the trainer.

\subsection{Device tokens, not credentials}

A station authenticates with a scoped, revocable per-device token rather than the owner's password, and
a collar holds nothing at all. A lost or compromised device therefore cannot expose the owner's
credentials, and it can be revoked simply by deleting its token from the account, with no password
change and no effect on the owner's other devices. The token is carried in an \texttt{Authorization}
header rather than a URL or query string, so it stays out of request logs, and the rules let an account
claim only an unclaimed token or one it already owns, so a known token cannot be re-pointed to another
account. \Cref{fig:token} traces the token's lifecycle.

\begin{figure}[ht]\centering
  \begin{tikzpicture}[node distance=10mm and 14mm, every node/.style={font=\footnotesize}]
    \node[mwterm] (mint) {Dashboard mints token T\\\scriptsize records \texttt{deviceTokens/T/owner}};
    \node[mwflow, below=of mint, text width=6.6cm, align=left] (store)
      {Station stores T in NVS and presents it on every cloud request (no login)};
    \node[mwflow, below=15mm of store, xshift=-26mm, text width=4cm, align=left] (rules)
      {Database rules: T maps to the owner, so writes to that owner's subtree are allowed};
    \node[mwflow, below=15mm of store, xshift=26mm, text width=4cm, align=left] (upl)
      {\texttt{upload\_clip} verifies T's owner and writes the clip as admin};
    \node[mwterm, below=38mm of store] (revoke) {Revoke: delete the token; all its access is denied};
    \draw[mwedge] (mint) -- (store);
    \draw[mwedge] (store) -- (rules);
    \draw[mwedge] (store) -- (upl);
    \draw[mwedge] (rules) -- (revoke);
    \draw[mwedge] (upl) -- (revoke);
  \end{tikzpicture}
  \caption{Credential-token lifecycle. A device is minted a scoped token that maps to its owner; the
           token authorises database writes and clip uploads, and deleting it revokes the device.}
  \label{fig:token}
\end{figure}

\subsection{Enforced read-only demo}

The public demo reads a single designated demo account's data, which the rules make world-readable, but
that account is write-locked at the backend: the demo cannot change any data or trigger any function.
The read-only behaviour is enforced by the rules, not merely hidden in the interface, so it holds even
against a hand-crafted client.

\subsection{Secret handling}

The Firebase web API key shipped in the static front end is a public client identifier, not a secret;
security is enforced by Authentication and the rules, not by hiding the key. No service-account key is
present in the repository, and the functions run on their ambient service account. Device Wi-Fi
credentials are entered at runtime and never committed, and \texttt{.gitignore} guards against any
local secret file. Everything required to understand and build the system is tracked; only true
secrets are not.

\subsection{Link encryption}

The collar-to-station Bluetooth link is encrypted. Both the audio stream and the over-the-air model
transfer require an encrypted connection (LE Secure Connections), established fresh on each connection so
a battery collar that reboots carries no stale pairing state. A nearby device that has not paired cannot
subscribe to the audio stream or write a model to the collar, so it can neither eavesdrop on the link nor
overwrite the model flash; an over-the-air image is in any case committed only after a CRC-32 integrity
check (\cref{sec:training-pipeline}). Authenticating the pairing against an active man-in-the-middle, with
a key provisioned over USB, is future work (\cref{sec:future-work}).

\subsection{Owner data rights}

The account page lets an owner export everything stored about their cats and delete their account,
devices, and data. This supports the access and erasure expectations of data-protection regimes such as
the UK GDPR. The bundled privacy policy is a starting point and is marked for legal review before any
public launch.

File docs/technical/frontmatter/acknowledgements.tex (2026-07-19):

% acknowledgements.tex , front-matter, unnumbered.
% \phantomsection makes the TOC hyperlink point to this page (needed for \section* + \addcontentsline).
\phantomsection
\addcontentsline{toc}{section}{Acknowledgements}
\section*{Acknowledgements}

Meowtion is the work of \textbf{Jerome Graves} and \textbf{Rose Delcour-Min}. It stands on a large body
of open-source work, the Zephyr and ESP-IDF projects, TensorFlow Lite Micro and CMSIS-NN, Firebase and
Streamlit, and the wider embedded and machine-learning communities whose tools made a two-person build
of this scope possible.

Our greatest debt, though, is to \textbf{Rupert}, the cat. He wore every awkward prototype without
complaint, treated each new collar as a minor inconvenience between naps, and, simply by being himself,
supplied the ground truth this entire system is built on. Every eating, drinking, grooming and resting
example in these pages traces back to him. He remains entirely unimpressed.

\clearpage

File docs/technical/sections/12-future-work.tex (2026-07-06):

\section{Future work}
\label{sec:future-work}

Meowtion already runs the whole loop on real hardware: capture, label, train, deliver over the air,
classify on the collar, and surface the result live. What follows is the roadmap from that working
system toward its real goal (noticing a cat's health change early), ordered so the near-term items
that finish the product come first and the research-scale ones last.

\begin{description}[leftmargin=1.6em,style=nextline]
  \item[From activity to health insight] The dashboard already tracks each habit and flags a large,
        sustained change against the cat's own baseline (\cref{sec:dashboard}). The next step is the
        health analytics the product is really about: baselines that adapt as the cat ages, anomaly
        detection over a multi-day trend rather than single events, and a concise, vet-shareable
        summary when a habit drifts. This is the shortest path from an activity tracker to a genuine
        early-warning tool, and it needs no new hardware.
  \item[Richer, per-cat recognition] Extend the labelled set beyond the current eat/drink/resting/moving to scratching,
        litter-tray use, grooming, and play, and add a short per-cat fine-tune pass so recognition
        sharpens for each animal's own motion and sound. Both fall straight out of the label-agnostic
        pipeline (\cref{sec:training-pipeline}).
  \item[Longer battery life] Add true hardware wake-on-motion (an IMU interrupt waking the SoC from
        System OFF) and tune the activity gate's thresholds and the audio path's duty cycle against
        the measured power budget (\cref{sec:evaluation}) for the lowest possible rest current.
  \item[Multiple cats and shared stations] Several cats are already supported, each on its own collar
        with per-cat data and a dashboard switcher. The open problems are \emph{model} generalisation
        (training on one cat and performing well on another, since the evaluation is currently
        single-cat and within-subject) and telling apart two cats that share a bowl or station.
  \item[Full firmware over the air] Today only models are delivered wirelessly; extend the same
        staged, CRC-checked mechanism (\cref{sec:protocols}) to complete firmware updates, so a
        deployed collar never needs a cable.
  \item[Field validation and publication] Move the accuracy study beyond a single cat with a larger,
        multi-household dataset, ideally paired with vet-confirmed events to test the early-warning
        claim directly, then write up the confidence-gated cascade as a preprint and a venue paper.
\end{description}

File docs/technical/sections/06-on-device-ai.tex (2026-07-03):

\section{On-device AI}
\label{sec:on-device-ai}

All classification happens on the collar in real time, using TensorFlow Lite
Micro~\cite{david2021tflm} with the CMSIS-NN kernels~\cite{lai2018cmsisnn} for the nRF52840's
Cortex-M4F. The models are tiny int8 networks in the spirit of TinyML~\cite{warden2019tinyml}: small
enough to fit a microcontroller's RAM and run within the collar's power budget, yet accurate enough to
separate everyday behaviours.

\subsection{Three-tier cascade}

Inference cost rises sharply across the cascade, so Meowtion gates each tier behind a cheaper one and
pays for the next only when the cheaper tier cannot answer. Three tiers run in front of every reported
behaviour:

\begin{enumerate}[leftmargin=1.6em,itemsep=2pt]
  \item \textbf{Rules-based activity gate} (no model). A cheap motion-energy rule on the raw IMU
        stream decides \emph{active} vs \emph{resting}. Most of a cat's day is rest, and classifying
        stillness 50 times a second drains the cell for no information, so sustained low motion drops
        the collar into low-power rest: the 104\,Hz sampling and inference stop, the IMU falls back to
        a low-power motion watch, and the radio slows. Motion ends rest, and the whole dormant span is
        reported as a single \emph{rest} episode (\cref{sec:firmware-collar}). This gate is the
        dominant battery lever (\cref{sec:evaluation}).
  \item \textbf{IMU model} (model-based). While the cat is active, the int8 motion model runs on every
        window. It is cheap and carries most of the classification load.
  \item \textbf{Audio model} (model-based). When the IMU model is \emph{unsure} (its top class falls
        below a confidence threshold of 0.75), the short audio model is invoked to confirm. Audio is
        therefore a deployed disambiguation signal, not merely a training aid.
\end{enumerate}

The audio tier earns its keep on one hard case: eating and drinking look almost identical to a motion
sensor (head down at a bowl, similar gross motion) but sound completely different. The cascade keeps
average power low at both ends , the rules-based gate suppresses all sensing and inference while the
cat rests, and the audio path runs only to break a tie , while still recovering accuracy that motion
alone cannot provide. The policy lives in plain C, independent of the inference backend: the
rules-based gate in \texttt{activity.c}, and the model-tier gating in \texttt{classifier.c}.
\Cref{fig:cascade} shows the decision flow.

\begin{figure}[ht]
  \centering
  \begin{tikzpicture}[node distance=8mm and 14mm]
    \node[mwterm] (win) {IMU stream};
    \node[mwdecision, below=of win] (act) {moving?};
    \node[mwflow, left=of act, text width=2.3cm] (rest) {Low-power rest\\\scriptsize rest event on wake};
    \node[mwflow, below=of act] (imu) {IMU model};
    \node[mwdecision, below=of imu] (q) {top class\\confident?};
    \node[mwterm, below=of q] (out1) {Report class\\+ confidence};
    \node[mwflow, right=of q] (aud) {Audio model};
    \node[mwterm, below=of aud] (out2) {Report\\confirmed class};
    \draw[mwedge] (win) -- (act);
    \draw[mwedge] (act) -- node[above,font=\scriptsize,text=mwmut]{no} (rest);
    \draw[mwedge] (act) -- node[right,font=\scriptsize,text=mwmut]{yes} (imu);
    \draw[mwedge] (rest.north) to[bend left=40] node[above,font=\scriptsize,text=mwmut]{motion} (win.west);
    \draw[mwedge] (imu) -- (q);
    \draw[mwedge] (q) -- node[left,font=\scriptsize,text=mwmut]{yes} (out1);
    \draw[mwedge] (q) -- node[above,font=\scriptsize,text=mwmut]{no} (aud);
    \draw[mwedge] (aud) -- (out2);
  \end{tikzpicture}
  \caption{The three-tier cascade. The rules-based activity gate runs first: while the cat is still
           the collar rests in low power and the dormant span is logged as one rest event; on motion
           the IMU model runs on every window, and the audio model is invoked only when the IMU
           model's top class is below the confidence threshold. With no model loaded the model tiers
           return \texttt{UNKNOWN}.}
  \label{fig:cascade}
\end{figure}

\subsection{Matching training and inference}

The on-device input transform must mirror the training transform exactly; this is the single most
important correctness property. A model trained on one representation and fed another at inference
produces confident nonsense. Meowtion enforces the match on both paths:

\begin{itemize}[leftmargin=1.5em]
  \item \textbf{Motion.} The rolling window is normalised per channel (subtract each channel's mean
        over the window, divide by the global maximum absolute value with a small epsilon) and
        quantised to int8 using the input tensor's own scale and zero-point.
  \item \textbf{Audio.} Inference audio is decimated and encoded to match the training
        representation: 8\,kHz $\mu$-law, produced by the same conversion used to prepare the training
        clips (\cref{sec:protocols}). A mismatch here was an early source of confident
        misclassification.
\end{itemize}

To avoid a large floating-point scratch buffer on a RAM-constrained part, the IMU path quantises
directly from the int16 source in a few passes (per-channel mean, then global max-abs, then write
int8) rather than materialising a float window (\cref{lst:quant}).

\begin{lstlisting}[language=C,caption={Direct int16-to-int8 quantisation, mirroring training (sketch).},label={lst:quant}]
// pass 1: per-channel mean over the window
// pass 2: global max-abs of (sample - channel_mean)
// pass 3: int8 = round( x_norm / scale ) + zero_point,
//         where x_norm = (sample - channel_mean) / (maxabs + 1e-6)
// scale and zero_point are read from the input tensor itself.
\end{lstlisting}

\subsection{Model architecture}

Each model stage is a small 1-D convolutional network trained in the cloud and exported as an int8
\texttt{.tflite} (\cref{sec:training-pipeline}). The IMU stage runs over a rolling window of motion
samples (six channels: accelerometer and gyroscope x/y/z); the audio stage runs over one second of
8\,kHz audio (8000 samples).

Both stages are the small 1-D CNNs defined in the training pipeline (\cref{sec:training-pipeline}).
Every convolution uses \texttt{same} padding and ReLU; with a stride $s$ the output length is
$\lceil L/s \rceil$. The classifier head has $N$ outputs, where $N$ is the number of action classes
discovered from the labelled data, so the head and the totals scale with $N$. The exported int8
model sizes are reported in \cref{tab:footprint}.

\begin{table}[ht]
  \centering
  \caption{Per-stage network architecture. \texttt{k}\,$=$\,kernel size, \texttt{s}\,$=$\,stride;
           $N$ is the action-class count (discovered from the data). Parameter counts are for the
           trained float model; export quantises weights to int8.}
  \label{tab:arch}
  \small
  \begin{tabular}{@{}lllr@{}}
    \toprule
    \textbf{Stage} & \textbf{Layer} & \textbf{Output} & \textbf{Params} \\
    \midrule
    IMU
      & Input                          & $104\times6$  & 0 \\
      & Conv1D 16, k5, s1, ReLU        & $104\times16$ & 496 \\
      & MaxPool1D 2                    & $52\times16$  & 0 \\
      & Conv1D 32, k5, s1, ReLU        & $52\times32$  & 2\,592 \\
      & MaxPool1D 2                    & $26\times32$  & 0 \\
      & Conv1D 64, k3, s1, ReLU        & $26\times64$  & 6\,208 \\
      & GlobalAvgPool1D                & $64$          & 0 \\
      & Dense 32, ReLU (Dropout 0.3)   & $32$          & 2\,080 \\
      & Dense $N$, Softmax             & $N$           & $33N$ \\
    \cmidrule(l){2-4}
      & \textbf{Total}                 &               & $11\,376 + 33N$ \\
    \midrule
    Audio
      & Input                          & $8000\times1$ & 0 \\
      & Conv1D 8, k9, s4, ReLU         & $2000\times8$ & 80 \\
      & Conv1D 16, k9, s4, ReLU        & $500\times16$ & 1\,168 \\
      & Conv1D 32, k5, s2, ReLU        & $250\times32$ & 2\,592 \\
      & Conv1D 32, k3, s2, ReLU        & $125\times32$ & 3\,104 \\
      & GlobalAvgPool1D                & $32$          & 0 \\
      & Dense 32, ReLU (Dropout 0.3)   & $32$          & 1\,056 \\
      & Dense $N$, Softmax             & $N$           & $33N$ \\
    \cmidrule(l){2-4}
      & \textbf{Total}                 &               & $8\,000 + 33N$ \\
    \bottomrule
  \end{tabular}
\end{table}

\subsection{Runtime models and model-free safety}

No model is compiled into the firmware. Each stage loads its \texttt{.tflite} at runtime
(\texttt{clf\_set\_imu\_model} / \texttt{clf\_set\_audio\_model}) from the dedicated flash partition,
delivered over the air (\cref{sec:firmware-collar,sec:protocols}), so a re-trained model swaps in
without reflashing. The engine is also safe with no model present: the presence queries return false
and the cascade returns \texttt{UNKNOWN} rather than a wrong answer. This is the state of a freshly
flashed collar before its first model arrives.

\subsection{Memory budget}

TensorFlow Lite Micro uses a fixed, statically allocated tensor arena (this firmware uses no heap).
The two stages never infer at once , the cascade runs the motion model first and consults audio only
when unsure , so rather than reserve an arena each, they share a \emph{single} arena: the collar loads
exactly one model into it at a time and unloads that model before arming the other, so only one
model's tensors are ever resident. The arena is sized to the larger (audio) stage; the smaller motion
model fits inside it. The value in \cref{tab:arenas} is a starting budget and must be tuned to the
real exported models, since an undersized arena makes \texttt{AllocateTensors()} fail and that stage
report itself absent.

\begin{table}[ht]
  \centering
  \caption{Shared tensor arena (initial budget).}
  \label{tab:arenas}
  \begin{tabularx}{\textwidth}{@{}llX@{}}
    \toprule
    \textbf{Arena} & \textbf{Size} & \textbf{Notes} \\
    \midrule
    Shared (one model resident) & 48\,KiB & Sized to the audio stage (1-D conv over 8000 points); the
      motion model loads into the same arena and fits. The two flip in and out on demand, so only one
      model's tensors occupy RAM at a time \\
    \bottomrule
  \end{tabularx}
\end{table}

Sharing one arena rather than two is a deliberate choice on the memory-bound collar: it saves the
second arena outright. Enabling inference initially pushed RAM use to roughly 94\,\%; eliminating the
float-window scratch buffer (quantising directly from int16) and sharing the single arena brought it
back into the mid-80s, leaving headroom for the BLE stack and the raised main stack
(\cref{sec:firmware-collar}).

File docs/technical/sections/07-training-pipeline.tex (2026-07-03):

\section{Training pipeline}
\label{sec:training-pipeline}

Meowtion learns new behaviours through a closed loop the owner drives entirely from the dashboard,
with no local toolchain: capture, label, train, deliver, run. The loop turns the collar from a
fixed-function sensor into a platform for recognising any behaviour the owner can demonstrate.

\subsection{Closed loop}

\begin{enumerate}[leftmargin=1.6em,itemsep=2pt]
  \item \textbf{Define behaviours.} The owner lists the actions to recognise (eat, drink, purr,
        scratch, litter-tray, and so on) in the dev console. This set drives both the clip-label
        dropdown and the trained model's outputs.
  \item \textbf{Capture.} With a station in training mode, paired audio and time-aligned motion are
        recorded while a registered collar is in range and uploaded to Cloud Storage (Flow~2,
        \cref{sec:architecture}).
  \item \textbf{Label.} The owner reviews clips in the dev console, sets each clip's action, trims
        dead space from the waveform, and discards poor examples.
  \item \textbf{Train.} The \texttt{train} Cloud Function trains the models server-side from the
        labelled clips and writes the results back: the quantised \texttt{.tflite} blobs to Cloud
        Storage, and the new version and label list to the Realtime Database.
  \item \textbf{Deliver.} Each station watches a model-version key; when it changes the station
        downloads the new \texttt{.tflite} files and pushes them to the collar over the air via the
        BEGIN/DATA/END/CRC sequence (\cref{sec:protocols}).
  \item \textbf{Run.} In production mode the collar classifies with the new model and the dashboard
        shows live, named behaviours. Observing those results, the owner captures more clips or adds
        behaviours and retrains, closing the loop: the collar's own data improves the model it runs
        (\cref{fig:training-loop}).
\end{enumerate}

\begin{figure}[ht]\centering
  \resizebox{0.66\textwidth}{!}{%
  \begin{tikzpicture}[every node/.style={font=\footnotesize}]
    \def\R{3.6}
    \node[mwflow] (define)  at (90:\R)   {\textbf{1.} Define\\behaviours};
    \node[mwflow] (capture) at (30:\R)   {\textbf{2.} Capture};
    \node[mwflow] (label)   at (-30:\R)  {\textbf{3.} Label};
    \node[mwflow] (train)   at (-90:\R)  {\textbf{4.} Train};
    \node[mwflow] (deliver) at (-150:\R) {\textbf{5.} Deliver\\{\scriptsize(OTA push)}};
    \node[mwflow] (run)     at (150:\R)  {\textbf{6.} Run};
    \node[align=center, text=mwmut, font=\itshape] at (0,0)
      {owner-driven loop\\[2pt]the collar supplies the data\\\emph{and} runs the model};
    \draw[mwedge] (define)  -- (capture);
    \draw[mwedge] (capture) -- (label);
    \draw[mwedge] (label)   -- (train);
    \draw[mwedge] (train)   -- (deliver);
    \draw[mwedge] (deliver) -- (run);
    \draw[mwedge] (run) -- node[midway, above left=-2pt, text=mwlavd, font=\bfseries\scriptsize]{iterate} (define);
  \end{tikzpicture}}
  \caption{The training pipeline closes into a loop. The same collar that captures the labelled data
           (steps 2--3) also runs the model trained from it (step 6); observing the live results, the
           owner refines or adds behaviours and retrains, so each pass improves the next. The loop is
           owner-driven (human-in-the-loop), not autonomous.}
  \label{fig:training-loop}
\end{figure}

\Cref{fig:capture-flow} shows how the training \emph{data} moves through the system during the capture
and label steps; \cref{fig:training-flow} (below) shows how the trained \emph{model} moves back out.

\begin{figure}[ht]\centering
  \resizebox{\textwidth}{!}{%
  \begin{tikzpicture}[node distance=12mm and 18mm, every node/.style={font=\footnotesize}]
    \node[mwnode] (collar) {Collar};
    \node[mwnode, right=of collar] (station) {Station};
    \node[mwnode, right=of station] (upl) {\texttt{upload\_clip()}};
    \node[mwnode, fill=mwlav!8, right=of upl] (store) {Storage\\\scriptsize training clips};
    \node[mwnode, fill=mwlav!8, below=15mm of station] (rtdb) {Realtime DB\\\scriptsize clip metadata};
    \node[mwnode, below=15mm of upl] (dev) {Dev console\\\scriptsize label $\cdot$ playback};
    \draw[mwedge] (collar) -- node[above,text=mwmut,font=\scriptsize]{BLE clip frames} (station);
    \draw[mwedge] (station) -- node[above,text=mwmut,font=\scriptsize]{POST (token)} (upl);
    \draw[mwedge] (upl) -- node[above,text=mwmut,font=\scriptsize]{write (admin)} (store);
    \draw[mwedge] (station) -- node[left,text=mwmut,font=\scriptsize]{metadata} (rtdb);
    \draw[mwedge] (rtdb) -- node[above,text=mwmut,font=\scriptsize]{read} (dev);
    \draw[mwedge] (store) -- node[right,text=mwmut,font=\scriptsize]{audio + IMU} (dev);
  \end{tikzpicture}}
  \caption{Training-data transport. The collar streams paired audio\,+\,IMU clip frames to the station,
           which slices them into clips and uploads the bytes through \texttt{upload\_clip} to Storage
           and the clip metadata to the database; the dev console reads both to play back, label, and
           train on them.}
  \label{fig:capture-flow}
\end{figure}

\subsection{The trainer}

Training runs in the \texttt{train} Python Cloud Function, currently gated to developer accounts to
keep cloud costs down during development rather than as an inherent limit (\cref{sec:cloud-backend}).
It reads the account's labelled clips (metadata from the Realtime
Database, audio and motion bytes from Cloud Storage) and derives the class set directly from the
labels present, so the network's outputs follow whatever behaviours the owner defined. It then trains
the two cascade stages independently:

\begin{itemize}[leftmargin=1.5em]
  \item a small 1-D convolutional network over the motion windows (six IMU channels), and
  \item a larger 1-D convolutional network over the 8\,kHz audio windows.
\end{itemize}

Each input is windowed with overlap and normalised exactly as the collar normalises it at inference,
so the on-device and training transforms match (\cref{sec:on-device-ai}). The trained Keras models are
converted to TensorFlow Lite with full int8 post-training quantisation using a representative dataset,
so the exported \texttt{.tflite} weights and activations are int8 and the input and output tensors
carry the scale and zero-point the collar uses to quantise its own inputs. \Cref{fig:training-flow}
shows the whole path, from the training trigger to the model running on the collar.

\begin{figure}[ht]
  \centering
  \begin{tikzpicture}[node distance=12mm, every node/.style={font=\footnotesize}]
    \node[mwterm] (dev) {Dev console: ``Train''};
    \node[mwflow, below=of dev, text width=6cm, align=left] (train)
      {\texttt{train()}: reads labelled clips (RTDB labels + Storage \texttt{wav}/\texttt{imu}); trains int8 IMU + audio models};
    \node[mwnode, fill=mwlav!8, below=15mm of train, xshift=-30mm, text width=3cm] (store)
      {Storage\\\texttt{models/<uid>/\allowbreak *.tflite}};
    \node[mwnode, fill=mwlav!8, below=15mm of train, xshift=30mm, text width=3cm] (rtdb)
      {Realtime DB\\\texttt{models}: version + labels};
    \node[mwflow, below=38mm of train] (station) {Station};
    \node[mwterm, below=12mm of station] (collar) {Collar: verify CRC, load model};
    \draw[mwedge] (dev) -- node[right,text=mwmut]{POST (dev token)} (train);
    \draw[mwedge] (train) -- (store);
    \draw[mwedge] (train) -- (rtdb);
    \draw[mwedge] (store) -- node[left,text=mwmut,pos=0.4]{download} (station);
    \draw[mwedge] (rtdb) -- node[right,text=mwmut,pos=0.4]{version bump} (station);
    \draw[mwedge] (station) -- node[right,text=mwmut]{OTA (BLE, CRC)} (collar);
  \end{tikzpicture}
  \caption{Training and over-the-air model delivery. \texttt{train()} reads the labelled clips, writes
           the quantised models to Storage and the new version and labels to the database, and the
           station detects the version bump, downloads the models, and pushes them to the collar.}
  \label{fig:training-flow}
\end{figure}

\subsection{Label-agnostic by design}

The trainer is not hard-coded to a fixed set of actions; it learns whatever label set the owner
defines. This makes Meowtion a platform rather than a fixed-function gadget: the same pipeline that
recognises eating and drinking can be pointed at any distinguishable behaviour the owner can capture
and label. The class set flows end to end as data, from the dashboard's action list, through the
trainer, to the index-based on-collar classifier, with names attached only at the edges.

\subsection{Delivery contract}

Training outputs are written to predictable locations so the station finds them without coordination:
the model blobs land in Cloud Storage as \texttt{models/<uid>/\allowbreak imu\_model.tflite} and
\texttt{models/<uid>/\allowbreak audio\_model.tflite}, the new version is mirrored into each of the owner's
stations' configuration so their version gate fires, and the label list is stored in
\texttt{users/<uid>/models} so the dashboard can map a class index back to a name across label-set
changes (\cref{sec:cloud-backend}).

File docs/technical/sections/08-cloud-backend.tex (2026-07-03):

\section{Cloud backend}
\label{sec:cloud-backend}

The backend is Firebase~\cite{firebase}, Google's hosted backend platform (sign-in, database, file
storage, and serverless functions). It provides owner authentication, a Realtime Database (RTDB)
for live state and history, Cloud Storage for training clips and model blobs, and Python Cloud
Functions (2nd generation) for server-side logic. There is no custom server to operate. The whole
backend lives in \texttt{app/firebase/} and deploys with \texttt{firebase deploy} from that folder.

\subsection{Authentication}

Owners sign in with Firebase Authentication (email/password or Google). The collar and station do
\emph{not} authenticate as users: a station carries a scoped per-device token, and a collar carries
nothing (the station relays it). The credential surface on battery devices is thus a single revocable
token (\cref{sec:security-privacy}).

\subsection{Backend data flow}

\Cref{fig:backend-flow} shows how the tiers exchange data in normal operation. The dashboard reads the
RTDB, both a small per-cat live read and a cached history read (\cref{sec:dashboard}). The station
writes telemetry and events to the RTDB and uploads training clips to Cloud Storage through the
\texttt{upload\_clip} function. The station also relays the collar and delivers models to it over BLE.
Clients never write Cloud Storage directly (\cref{sec:security-privacy}). The training path that
produces those models appears separately in \cref{fig:training-flow}.

\begin{figure}[ht]
  \centering
  \resizebox{0.92\textwidth}{!}{%
  \begin{tikzpicture}[node distance=13mm and 32mm, every node/.style={font=\footnotesize}]
    \node[mwnode] (dash) {Dashboard};
    \node[mwnode, below=14mm of dash] (station) {Station};
    \node[mwnode, below=14mm of station] (collar) {Collar};
    \node[mwnode, fill=mwlav!8, right=of dash] (rtdb) {Realtime Database\\\scriptsize current, events, models, config};
    \node[mwnode, fill=mwlav!8, right=of station] (store) {Cloud Storage\\\scriptsize clips, models};
    \draw[mwedge] (rtdb) -- node[above,text=mwmut]{read (live + history)} (dash);
    \draw[mwedge] (station) -- node[above,pos=0.55,text=mwmut]{telemetry, events} (rtdb);
    \draw[mwbiedge] (station) -- node[below,align=center,xshift=-5mm,text=mwmut]{clips (via \texttt{upload\_clip});\\download models} (store);
    \draw[mwbiedge] (collar) -- node[left,text=mwmut]{BLE relay / OTA} (station);
  \end{tikzpicture}}
  \caption{Backend data flow in normal operation. The dashboard reads the database; the station writes
           live state and events and uploads clips; the collar is relayed and updated through the
           station.}
  \label{fig:backend-flow}
\end{figure}

\subsection{Realtime Database schema}

State and history live in the RTDB, keyed by owner so the security rules scope every read and write to
the owning account. \Cref{tab:db} lists the main paths.

\begin{table}[ht]
  \centering
  \caption{Realtime Database paths.}
  \label{tab:db}
  \begin{tabularx}{\textwidth}{@{}lX@{}}
    \toprule
    \textbf{Path} & \textbf{Contents} \\
    \midrule
    \texttt{users/<uid>/devices/<token>}        & A registered station (\texttt{type:station}) with its
      relayed \texttt{cats/<catId>} subtree, or a registered collar entry \\
    \texttt{.../cats/<catId>/current}           & The cat's live state (version, class, confidence, steps, battery) plus the station-measured signal (\texttt{rssi}) and \texttt{proximity} , the single source for the dev console's presence view \\
    \texttt{.../cats/<catId>/events}            & Discrete activity events (carry model version + class index) \\
    \texttt{.../devices/<station>/weather}      & Current and recent local weather for the station's location \\
    \texttt{users/<uid>/models}                 & Current model version, status, and the label list \\
    \texttt{users/<uid>/actions}                & The behaviours to recognise (managed from the dev console) \\
    \texttt{deviceTokens/<token>/owner}         & Maps a device token to its owning account \\
    \texttt{config/demoOwner}                   & UID whose data backs the public read-only demo \\
    \texttt{config/devAccounts/<uid>}           & Accounts allowed to use the dev/training tools \\
    \bottomrule
  \end{tabularx}
\end{table}

Events store the model version and class index rather than a pre-resolved name. The dashboard maps the
index to a label using that version's label list, so historical events stay correct as the owner
changes their behaviour set.

\subsection{Cloud Storage}

Cloud Storage holds the training clips (audio plus aligned motion) and the trained model blobs in an
owner-scoped layout: clips at \texttt{training/<owner>/\allowbreak <collar>/<ts>.\{wav,imu\}} and models
at \texttt{models/<uid>/\allowbreak \{imu,audio\}\_model.tflite}. Training clips are private to the owner
and \emph{not} world-readable, even in the demo, because home audio must never be public. Model blobs
are public-read so the token-only station can fetch one to push to the collar, and are written only by
the trainer.

\subsection{Cloud Functions}

Two request functions handle the owner-facing server-side logic, and the demo simulator (below) is a
third, scheduled function. All run on the function's ambient service account, so no service-account
key is in the repository.

\begin{description}[leftmargin=1.6em,style=nextline]
  \item[\texttt{train}] Server-side model training, \texttt{POST} with a developer account's Firebase
        ID token and gated additionally by \texttt{config/devAccounts/<uid>}. It reads the account's
        labelled clips, trains the int8 IMU and audio models (\cref{sec:training-pipeline}), uploads
        them to \texttt{models/<uid>/}, updates \texttt{users/<uid>/models}, and mirrors the new
        version into each of the owner's station configs to trigger delivery.
  \item[\texttt{upload\_clip}] Authenticated clip upload for the token-only station. The station has
        no login, so it cannot satisfy the Cloud Storage rules directly. It POSTs the clip bytes here
        with its device token; the function verifies \texttt{deviceTokens/<token>/owner} and writes the
        file as administrator into that owner's area. The rules can then deny all direct client writes
        while still admitting an authorised station.
\end{description}

\subsection{Demo data simulator}

So the public demo always presents a populated, believable dashboard, a scheduled Cloud Function
maintains a fully simulated companion collar (``Purrminator'') on the demo account. It is standalone:
no station, always online. On first run it backfills roughly six months of realistic activity history,
weighted by time of day to match an average cat (crepuscular, busy around dawn and dusk, resting
overnight), with matching daily weather from a free historical feed. Thereafter it wakes on a short
schedule and commits each activity as an event when that action ends, so new events arrive at varying
intervals. The simulator writes only the demo account's own data and never touches a real collar.

\subsection{Weather context}

Local weather lets the dashboard read a habit change against its environment, since a warm spell that
raises drinking and suppresses appetite should not be mistaken for illness. The station polls a keyless
forecast feed (Open-Meteo) for its provisioned location and writes current and recent weather under its
device record. The demo simulator backfills weather from the same provider's historical archive
alongside the simulated activity.

\subsection{Configuration trust boundary}

The \texttt{config} subtree is never client-writable and is maintained from the Firebase console.
Reads are scoped to just what a client needs: \texttt{config/demoOwner} is public (it backs the demo)
and a signed-in user may read only their own \texttt{config/devAccounts/<uid>} flag, so the developer
list cannot be enumerated and a client still cannot grant itself privileges.

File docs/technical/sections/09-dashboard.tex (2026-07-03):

\section{Dashboard}
\label{sec:dashboard}

The owner-facing application is a dashboard built with Streamlit~\cite{streamlit} (a Python framework
for data web apps), backed by a small set of static
pages for the parts that need the Firebase web SDK directly (sign-in, account and device management,
the developer/training console, and the privacy policy). It is hosted on Streamlit Community Cloud and
deploys automatically from the repository's main branch.

\subsection{Hybrid front end}

Device registration needs the browser's Web Serial API, which cannot run in Streamlit's Python or its
sandboxed component iframes, and authentication is easiest with the Firebase web SDK in the browser.
The data views and charts, by contrast, are easiest in Streamlit's Python. Meowtion therefore serves
both halves from the same origin so they share a login: the static sign-in page writes the Firebase ID
token into a same-origin cookie, and the Python dashboard reads that cookie to identify the owner.

\begin{table}[ht]
  \centering
  \caption{Dashboard surfaces.}
  \label{tab:dash}
  \begin{tabularx}{\textwidth}{@{}llX@{}}
    \toprule
    \textbf{Surface} & \textbf{Tech} & \textbf{Role} \\
    \midrule
    \texttt{app.py}       & Streamlit/Python & Live cat state, activity history, health analytics \\
    \texttt{account.html} & JavaScript       & Sign-in, account management, device pairing over Web Serial \\
    \texttt{dev.html}     & JavaScript       & Developer/training console: capture, label, train, mode \\
    \texttt{privacy.html} & JavaScript       & Privacy policy \\
    \bottomrule
  \end{tabularx}
\end{table}

\subsection{Navigation}

The product is built around a single hub, the static front door. From it the owner signs in to the
dashboard, opens the developer console (if their account is enabled for it), or enters the read-only
demo; logging out returns there. \Cref{fig:pageflow} shows the navigation. A shared visual style, a
white canvas with lavender accents and collapsible cards, runs across every surface.

\begin{figure}[ht]
  \centering
  \resizebox{\textwidth}{!}{%
  \begin{tikzpicture}[node distance=7mm and 24mm]
    \node[mwterm] (front) {Front door\\\footnotesize account.html};
    \node[mwnode, right=of front, yshift=13mm] (dash) {Dashboard\\\footnotesize app.py};
    \node[mwnode, right=of front] (dev) {Dev console\\\footnotesize dev.html};
    \node[mwnode, right=of front, yshift=-13mm] (demo) {Read-only demo};
    \draw[mwbiedge] (front) -- node[above,font=\scriptsize,text=mwmut]{sign in / log out} (dash);
    \draw[mwedge] (front) -- node[above,font=\scriptsize,text=mwmut]{dev account} (dev);
    \draw[mwedge] (front) -- node[below,font=\scriptsize,text=mwmut]{view demo} (demo);
  \end{tikzpicture}%
  }
  \caption{Dashboard page flow. The static front door is the hub for sign-in, the developer console,
           and the read-only demo.}
  \label{fig:pageflow}
\end{figure}

\begin{figure}[ht]
  \centering
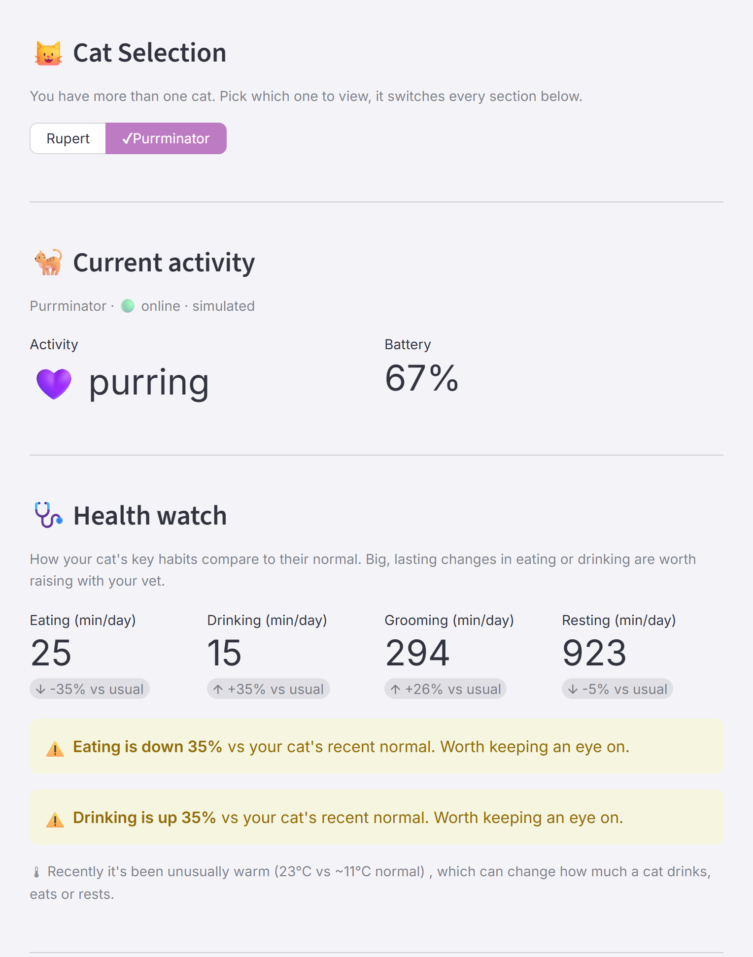
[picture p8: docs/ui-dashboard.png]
  
  \caption{The dashboard (read-only demo): the collar switcher, the live current-state card, and the
           Health watch flagging a warm-weather rise in drinking.}
  \label{fig:ui-dash}
\end{figure}

\subsection{Login and session}

The owner logs in once on the front door with Firebase Auth, which writes the ID token into a
same-origin cookie (\texttt{mtoken}). \texttt{app.py} reads that cookie client-side with the
\texttt{extra-streamlit-components} cookie manager rather than the server-side cookie API, because
Streamlit Community Cloud does not expose browser cookies to the server. Logged-out visitors get a
sign-in gate and never see the dashboard. Logging out navigates to the front door, signs out of
Firebase, and clears the cookie. No token is ever placed in a URL. A separate flag cookie marks the
public read-only demo.

\subsection{Code structure}

\texttt{app.py} is a thin entry point that wires the pieces in order (theme, sign-in, live cards,
analytics). Everything else is split into a \texttt{meowtion\_dash} package so the analytics view can
be edited without touching login or data-formatting code: \texttt{theme} (page config and brand
header), \texttt{auth} (cookie/JWT to \texttt{(uid, token, is\_demo)}), \texttt{firebase} (cached
RTDB reads), \texttt{data} (the clean activity DataFrame and filter helpers), \texttt{charts}
(branded Altair charts), \texttt{live} (the live current-state cards), and \texttt{weather}. The
editable analytics live in \texttt{dashboard\_view.py}, which receives a ready, one-row-per-event
pandas DataFrame and never sees a cookie or raw Firebase JSON.

\subsection{Live view versus history}

The two reads have very different needs and are split accordingly. The live current-state card
refreshes every few seconds but needs only each cat's \texttt{current} record and its most recent
events, so it issues a small per-cat read. The full activity history (potentially months of events) is
fetched on a longer cache interval and reused across refreshes. This keeps the fast-refreshing live
card from re-downloading the whole history on every tick, holding the page light and backend bandwidth
low.

\subsection{Health analytics}

The analytics view is built around health, not just a live read-out. A \emph{health watch} compares
each key habit (eating, drinking, grooming, resting) over recent days against the cat's own longer-run
baseline, and flags a sustained change with a plain-language, vet-oriented note rather than a
diagnosis. Two design choices keep it honest. It compares whole days only, since events are logged
when an action ends and the current day is always partial. And it pairs a flagged change with local
weather context, so a warm-spell rise in drinking is presented with its likely cause rather than as an
alarm. Below the health watch, a calendar date picker selects a single day or a date range; the view
auto-derives the granularity (a single day, or multiple days) from the chosen span. It then shows a
\emph{time per activity} bar chart (total minutes per behaviour over the selected window) above a
rows-of-days timeline, in which each event is a coloured bar drawn at the time of day it occurred
(y-axis: calendar day; x-axis: time of day). The timeline supports horizontal zoom (scroll or drag)
with a reset-view control, and its x-axis spans the data's actual time range rather than a fixed
24~hours. Colours are assigned from a colourblind-safe palette and shared between the activity filter
buttons (outline when off, filled when on) and both charts, and everything is rendered on a
transparent background so it sits on the page's brand canvas.

\begin{figure}[ht]
  \centering
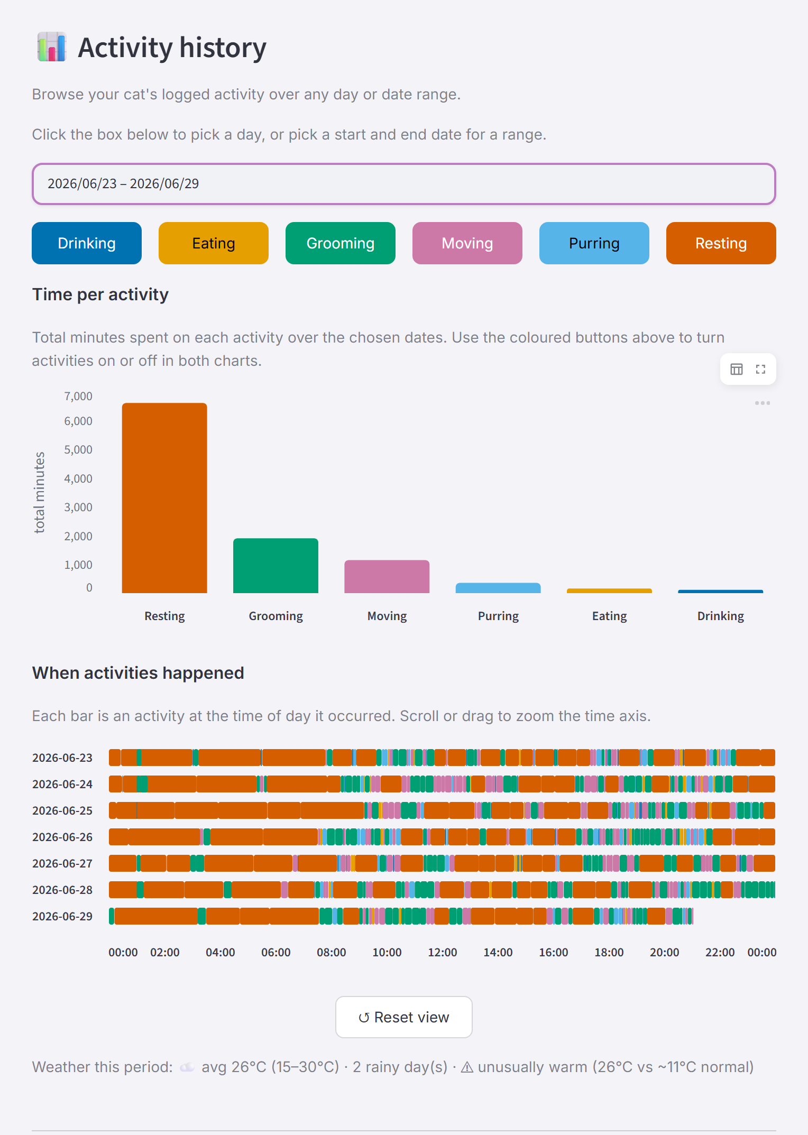
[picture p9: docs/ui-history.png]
  
  \caption{The history view (read-only demo): the calendar date picker, the per-activity time totals,
           and the zoomable rows-of-days activity timeline, with weather context.}
  \label{fig:ui-history}
\end{figure}

\subsection{Developer console}

\texttt{dev.html} is visible only to developer accounts and is the data-collection and training
control panel: live per-station capture status (signal, recording state, collar battery); the
Training/Production mode switch; the editable list of actions to recognise; the labelled-clip review
with waveform trimming; dataset statistics and a motion-variety measure to gauge whether a class has
enough varied examples; and the button that triggers cloud training. It also offers a full-screen,
phone-style capture view with large action buttons for live labelling at the bowl.

\begin{figure}[ht]
  \centering
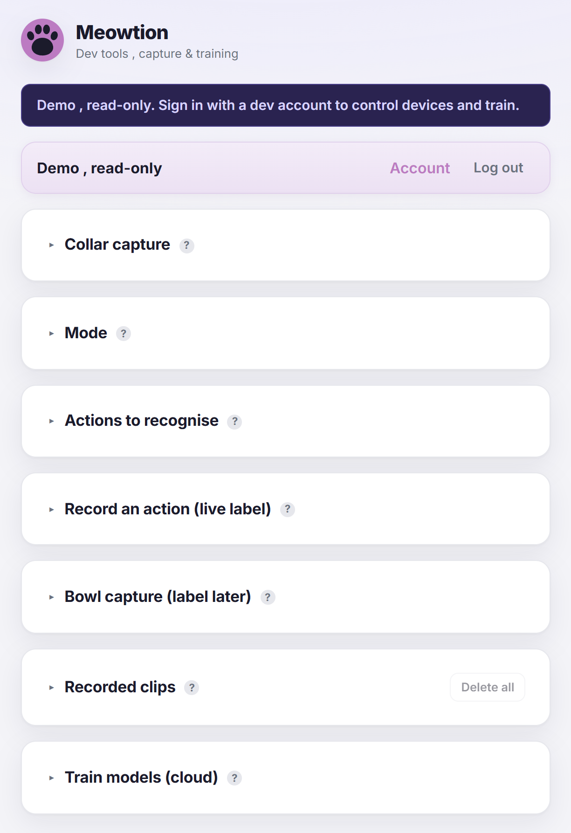
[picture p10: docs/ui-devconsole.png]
  
  \caption{The developer console (read-only demo): the capture, mode, actions, clip-review, and
           cloud-training sections (cards collapsed by default).}
  \label{fig:ui-dev}
\end{figure}

\subsection{Read-only demo}

A public demo lets anyone explore a populated product without an account. It reads the designated demo
owner's data, which the security rules make world-readable, but every write control and function
trigger is disabled and the dev console is available only in a read-only variant. The demo is read-only
because the backend rules enforce it, not because the interface hides the controls
(\cref{sec:security-privacy}).

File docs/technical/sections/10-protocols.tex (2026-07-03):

\section{Communication protocols}
\label{sec:protocols}

Four contracts tie the tiers together: the BLE telemetry the collar advertises, the audio clip-frame
format it streams during training, the over-the-air model protocol, and the cloud HTTP it is all
relayed over. The BLE wire formats are defined once in shared headers
(\texttt{firmware/common/meow\_protocol.h} and \texttt{meow\_ota.h}) that \emph{both} firmwares
include, so the collar (Zephyr) and station (ESP-IDF) builds cannot drift out of sync.

\subsection{Telemetry advertisement}

In production mode the collar publishes its result in the manufacturer-specific field of its BLE
advertisement, so the station can read it passively without connecting. The packet is eight bytes
(\cref{tab:telemetry}). The collar's BLE address identifies which collar it is, so the payload carries
no identifier. The \texttt{version} byte selects how the two result bytes are read: version~1 is the
simulated behaviour state machine, version~2 is real on-device classification.

\begin{table}[ht]
  \centering
  \caption{Eight-byte telemetry packet (manufacturer AD data).}
  \label{tab:telemetry}
  \begin{tabularx}{\textwidth}{@{}llX@{}}
    \toprule
    \textbf{Bytes} & \textbf{Field} & \textbf{Meaning} \\
    \midrule
    0--1 & company id   & \texttt{0xFFFF} (test/development identifier) \\
    2    & version      & \texttt{1} = simulated state, \texttt{2} = real on-device classification \\
    3    & state\,/\,class & v1: state (0 sleep \dots 5 groom); v2: predicted class index (\texttt{0xFE} = low-power rest, \texttt{0xFF} = unknown) \\
    4    & activity\,/\,confidence & v1: activity level 0--100; v2: confidence 0--100 \\
    5--6 & steps        & step count, \texttt{uint16}, little-endian \\
    7    & battery      & battery level 0--100 \\
    \bottomrule
  \end{tabularx}
\end{table}

Because the class is an index, not a name, the station and dashboard resolve it through the running
model version's label list, which keeps history correct across label-set changes
(\cref{sec:cloud-backend}). The reserved class \texttt{0xFE} marks low-power rest: the rules-based
activity gate advertises it while the collar sleeps, and the station records the span as a single
rest episode (\cref{sec:firmware-collar}).

\subsection{Audio clip-streaming frame}

While a station is subscribed in training mode, the collar streams continuously on the audio
characteristic in 100\,ms frames. Each frame is a packed header followed by an audio payload and a
time-aligned IMU payload. The station concatenates frames and slices them into fixed-length training
clips.

\begin{lstlisting}[language=C,caption={Clip-frame header (\texttt{firmware/common/meow\_protocol.h}).},label={lst:clip}]
#define MEOW_CLIP_MAGIC 0x574F454Du   /* 'MEOW' little-endian, marks each frame start */

struct __attribute__((packed)) meow_clip_hdr {
    uint32_t magic;
    uint8_t  version;      /* 1 = 16-bit PCM audio, 2 = 8-bit G.711 mu-law */
    uint8_t  imu_axes;     /* 6 = accel x/y/z + gyro x/y/z */
    uint16_t imu_rate_hz;
    uint32_t audio_bytes;  /* audio payload size (one 100 ms frame) */
    uint32_t imu_bytes;    /* IMU payload size */
    uint32_t audio_rate;   /* output sample rate, for the station's WAV header */
};
/* frame layout:  [ meow_clip_hdr ][ audio payload ][ IMU payload ] */
\end{lstlisting}

To halve the data on the BLE link the collar encodes audio as 8-bit G.711 $\mu$-law (\texttt{version}
2); the station decodes it back to 16-bit PCM for a normal WAV. The $\mu$-law codec is defined inline
in the same shared header, so the collar encode and station decode match. This is also the
representation the model is trained and run on (\cref{sec:on-device-ai}).

\subsection{GATT services}

The collar exposes two custom 128-bit GATT services that share a common Meowtion base UUID: the
\emph{audio} service for clip streaming, and the \emph{OTA} service for model delivery. The OTA service
uses three UUIDs distinguished by a \texttt{0x0b}\,$\ast\ast$ group, one each for its control, data,
and status characteristics. Both firmwares derive these UUIDs from the same header, the collar through
Zephyr's encoding macro and the station from the raw little-endian byte arrays the header also
provides.

\subsection{Over-the-air model protocol}

Model delivery is a small framed protocol over the OTA service. The client (station) writes opcodes to
the \emph{control} characteristic, streams the model to the \emph{data} characteristic, and the collar
acknowledges on a \emph{status} notification. A transfer is \texttt{BEGIN} (carrying the target slot,
total length, and a CRC), then a stream of write-with-response \texttt{DATA} chunks (each chunk's write
response is the flash-write flow control), then \texttt{END}. The collar erases the slot on
\texttt{BEGIN}, writes chunks as they arrive, and on \texttt{END} re-reads the model from flash,
verifies the CRC against the announced value, and reports the outcome.

\begin{lstlisting}[language=C,caption={OTA control opcodes, BEGIN payload, and status codes (\texttt{firmware/common/meow\_ota.h}).},label={lst:ota}]
/* CONTROL characteristic: first byte is an opcode; BEGIN is followed by meow_ota_begin. */
enum { MEOW_OTA_OP_BEGIN = 1, MEOW_OTA_OP_END = 2, MEOW_OTA_OP_ABORT = 3 };

struct __attribute__((packed)) meow_ota_begin {
    uint8_t  slot;       /* 0 = IMU model, 1 = audio model */
    uint32_t total_len;  /* model size in bytes */
    uint32_t crc32;      /* CRC-32/IEEE over the model blob */
};

/* STATUS characteristic (notify): the collar's acknowledgement. */
enum { MEOW_OTA_ST_READY = 1, MEOW_OTA_ST_RECEIVING = 2, MEOW_OTA_ST_OK = 3,
       MEOW_OTA_ST_ERR_SIZE = 5, MEOW_OTA_ST_ERR_CRC = 7, MEOW_OTA_ST_ERR_SEQ = 8 };
\end{lstlisting}

\texttt{END} verifies and stages the model but does \emph{not} swap the live model from inside the BLE
callback. Committing a model is stack-heavy, and doing it in the radio callback crash-looped the
device. The swap is therefore deferred to a service call on the main thread's larger stack
(\cref{sec:firmware-collar}). That split, with the raised main stack, is what made OTA reliable on
hardware. A persisted slot magic marks a slot that holds a valid committed model, so the collar can
tell an empty slot from a written one across a reboot. \Cref{fig:ota-seq} shows the message exchange.

\begin{figure}[ht]\centering
  \resizebox{0.94\textwidth}{!}{%
  \begin{tikzpicture}[font=\footnotesize]
    \node[mwterm] (s) at (0,0) {Station (client)};
    \node[mwterm] (c) at (8,0) {Collar (server)};
    \draw[draw=mwline,line width=0.6pt] (s) -- (0,-6);
    \draw[draw=mwline,line width=0.6pt] (c) -- (8,-6);
    \draw[mwedge] (0,-1.0) -- node[above,font=\scriptsize]{\texttt{BEGIN} (slot, total\_len, crc32)} (8,-1.0);
    \draw[mwedge] (8,-1.9) -- node[above,font=\scriptsize]{\texttt{READY} (slot erased)} (0,-1.9);
    \draw[mwedge] (0,-2.8) -- node[above,font=\scriptsize]{\texttt{DATA} chunk (write-with-response)} (8,-2.8);
    \node[font=\scriptsize,text=mwmut] at (4,-3.3) {(repeated for every chunk)};
    \draw[mwedge] (0,-4.2) -- node[above,font=\scriptsize]{\texttt{END}} (8,-4.2);
    \draw[mwedge] (8,-5.1) -- node[above,font=\scriptsize]{\texttt{OK} (CRC verified, model loaded)} (0,-5.1);
  \end{tikzpicture}}
  \caption{OTA model-push message sequence on the OTA service. The station writes \texttt{BEGIN},
           streams the model in write-with-response \texttt{DATA} chunks, then writes \texttt{END}; the
           collar erases the slot, receives the bytes, verifies the CRC, loads the model, and
           acknowledges on the status characteristic.}
  \label{fig:ota-seq}
\end{figure}

\subsection{Cloud transport}

Above BLE, the station speaks ordinary HTTPS to Firebase: it writes telemetry to the Realtime Database
(RTDB) through its REST interface, authorised by its device token, and POSTs training-clip bytes to the
\texttt{upload\_clip} Cloud Function carrying that token in an \texttt{Authorization: Bearer} header so
it stays out of the URL and request logs (\cref{sec:cloud-backend}). The dashboard is a separate client
of the same RTDB. No bespoke transport or message broker is involved; the contract at this tier is just
the RTDB schema and the function's request format.

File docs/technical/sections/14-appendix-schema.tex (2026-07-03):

\section{Data-model reference}
\label{sec:appendix-schema}

A consolidated reference for the cloud data model introduced in \cref{sec:cloud-backend}: the Realtime
Database tree, the Cloud Storage layout, and the request format of the HTTP Cloud Functions.

\subsection{Realtime Database tree}

\begin{lstlisting}[numbers=none,caption={Realtime Database layout (owner-scoped).},label={lst:rtdb}]
users/<uid>/
  devices/
    <stationToken>/            type: "station"
      cats/<catId>/
        current                { ver, cls, conf, steps, battery, ts, rssi, proximity }
        events/<startMs>        { start, durationSec, type | cls, ver }
      weather/                  { current, history }
      config/                   { modelVer, mode, captureForce, ... }
      seen/<collarId>           unregistered collars heard nearby
    <collarId>/                 type: "collar"  (registry entry; name, simulated)
  models/                       { version, status, labels[], results }
  actions/                      behaviours to recognise (dev console)
  profile/                      { consent, location }
deviceTokens/<token>/owner      maps a device token to its owning account
config/
  demoOwner                     uid backing the public read-only demo
  devAccounts/<uid>             accounts allowed to use the dev/training tools
\end{lstlisting}

Events store the model \texttt{version} and class \texttt{cls} index rather than a resolved name; the
dashboard maps the index to a label through that version's \texttt{labels} list, so history stays
correct across label-set changes. Low-power rest spans from the activity gate are logged the same way
but carry \texttt{type:\,"rest"} instead of a model class, so the timeline accounts for the resting
period rather than leaving a gap (\cref{sec:firmware-collar}).

The \texttt{current} record is the single live-state object per cat, written by the station. The owner
dashboard reads its class and battery; the developer console reads the \emph{same} record's
station-measured \texttt{rssi} and \texttt{proximity} (\texttt{recording} / \texttt{inRange} /
\texttt{approaching} / \texttt{away}). Presence and signal therefore have one source of truth rather
than a separate node for the console to reconcile against the relay.

\subsection{Cloud Storage layout}

\begin{lstlisting}[numbers=none,caption={Cloud Storage layout.},label={lst:storage}]
training/<owner>/<collar>/<ts>.wav    training-clip audio   (private to owner; no client writes)
training/<owner>/<collar>/<ts>.imu    time-aligned motion   (private to owner)
models/<uid>/imu_model.tflite         trained IMU model     (public-read; written by train only)
models/<uid>/audio_model.tflite       trained audio model   (public-read; written by train only)
\end{lstlisting}

\subsection{Cloud Function requests}

\begin{description}[leftmargin=1.6em,style=nextline]
  \item[\texttt{train}] \texttt{POST} with header \texttt{Authorization: Bearer <Firebase ID token>}
        of a developer account. Trains from the account's labelled clips; returns the new version and
        label set. Gated additionally by \texttt{config/devAccounts/<uid>}.
  \item[\texttt{upload\_clip}] \texttt{POST} the raw clip bytes with header
        \texttt{Authorization: Bearer <device token>} (kept out of the URL/query string). The function
        resolves \texttt{deviceTokens/<token>/owner} and writes the file as administrator into that
        owner's Storage area. No Firebase login is involved.
  \item[\texttt{simulate\_now}] \texttt{POST} with header \texttt{Authorization: Bearer <Firebase ID
        token>} of a developer account; manually kicks a demo-simulator run (the simulator otherwise
        runs on a per-minute schedule). Gated by \texttt{config/devAccounts/<uid>}.
\end{description}

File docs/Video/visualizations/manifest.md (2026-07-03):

# Video visualisations , slide map

Generated SVGs in this folder, one per concept-bearing slide. Named `<Deck>_slideNN.svg`, traceable to the PowerPoint deck and slide number.

| File | Deck | Slide | Concept | Slide script |
|---|---|---|---|---|
| `MeowtionAI_slide02.svg` | MeowtionAI | 2 | On-device classification | All classification happens on the collar in real time |
| `MeowtionAI_slide03.svg` | MeowtionAI | 3 | Confidence-gated cascade | Meowtion runs a confidence-gated cascade of two models |
| `MeowtionAI_slide04.svg` | MeowtionAI | 4 | Two-model cascade | Meowtion runs a confidence-gated cascade of two models |
| `MeowtionAI_slide05.svg` | MeowtionAI | 5 | Looks same, sounds different | behaviours that look identical to a motion sensor but sound completely different |
| `MeowtionAI_slide06.svg` | MeowtionAI | 6 | The IMU model | The IMU model |
| `MeowtionAI_slide07.svg` | MeowtionAI | 7 | Runs continuously | The IMU model runs continuously |
| `MeowtionAI_slide08.svg` | MeowtionAI | 8 | On the motion stream | The IMU model runs continuously on the motion stream |
| `MeowtionAI_slide09.svg` | MeowtionAI | 9 | It is cheap | It is cheap |
| `MeowtionAI_slide10.svg` | MeowtionAI | 10 | Always on | Always on |
| `MeowtionAI_slide11.svg` | MeowtionAI | 11 | Most of the load | And carries most of the classification load |
| `MeowtionAI_slide12.svg` | MeowtionAI | 12 | When the IMU is unsure | when the IMU is unsure |
| `MeowtionAI_slide13.svg` | MeowtionAI | 13 | Audio confirms | the short audio model is invoked to confirm class |
| `MeowtionAI_slide14.svg` | MeowtionAI | 14 | A deployed signal | audio is a deployed disambiguation signal, not merely a training aid |
| `MeowtionAI_slide15.svg` | MeowtionAI | 15 | Low power, recovered accuracy | keeps average power low while recovering accuracy motion alone cannot provide |
| `MeowtionAI_slide17.svg` | MeowtionAI | 17 | Defined from the dashboard | Meowtion learns new behaviours defined by the human, entirely from the dashboard, no local toolchain |
| `MeowtionAI_slide18.svg` | MeowtionAI | 18 | No local toolchain | Meowtion learns new behaviours defined by the human, entirely from the dashboard, no local toolchain |
| `MeowtionAI_slide19.svg` | MeowtionAI | 19 | Training loop: Capture | capture |
| `MeowtionAI_slide20.svg` | MeowtionAI | 20 | Training loop: Label | label |
| `MeowtionAI_slide21.svg` | MeowtionAI | 21 | Training loop: Train | train |
| `MeowtionAI_slide22.svg` | MeowtionAI | 22 | Training loop: Deliver | deliver |
| `MeowtionAI_slide23.svg` | MeowtionAI | 23 | Training loop: Run | run |
| `MeowtionAI_slide24.svg` | MeowtionAI | 24 | The training loop | the loop turns the collar from a fixed-function sensor into a platform for any behaviour |
| `MeowtionAI_slide25.svg` | MeowtionAI | 25 | Cloud training function | training runs in the train Python cloud function |
| `MeowtionAI_slide26.svg` | MeowtionAI | 26 | Classes from the labels | it reads the account's labelled clips and derives the class set from the labels present |
| `MeowtionAI_slide27.svg` | MeowtionAI | 27 | Two stages, trained apart | it then trains the two cascade stages independently |
| `MeowtionAI_slide28.svg` | MeowtionAI | 28 | Independent training | it then trains the two cascade stages independently |
| `MeowtionAI_slide29.svg` | MeowtionAI | 29 | End to end | the whole path, from the training trigger to the model running on the collar |
| `MeowtionIntro_slide04.svg` | MeowtionIntro | 4 | The system | an AI-powered smart collar that reads kitty's health from daily habits |
| `MeowtionIntro_slide05.svg` | MeowtionIntro | 5 | Live dashboard | viewable for humans from a live dashboard |
| `MeowtionIntro_slide07.svg` | MeowtionIntro | 7 | Cats hide illness | cats can hide their illness and pain so well |
| `MeowtionIntro_slide08.svg` | MeowtionIntro | 8 | Missed until serious | even the most attentive human can miss things until things get really serious |
| `MeowtionIntro_slide10.svg` | MeowtionIntro | 10 | Outdoors is a blind spot | you don't know what kitty gets up to when kitty goes outside |
| `MeowtionIntro_slide11.svg` | MeowtionIntro | 11 | On-device collar | a lightweight, battery-powered collar that classifies activities on-device with motion and audio |
| `MeowtionIntro_slide12.svg` | MeowtionIntro | 12 | Two quantised networks | using a confidence-gated cascade of two quantised neural networks |
| `MeowtionIntro_slide13.svg` | MeowtionIntro | 13 | Humans define it | humans define what to recognise |
| `MeowtionIntro_slide14.svg` | MeowtionIntro | 14 | Cloud trainer delivers | a cloud trainer delivers new models |
| `MeowtionIntro_slide15.svg` | MeowtionIntro | 15 | Back to the collar | back to the collar |
| `MeowtionIntro_slide16.svg` | MeowtionIntro | 16 | Over the air | over the air |
| `MeowtionIntro_slide18.svg` | MeowtionIntro | 18 | End to end on hardware | a complete system, demonstrated end to end on real hardware |
| `MeowtionIntro_slide19.svg` | MeowtionIntro | 19 | Private by design | a blueprint for private health monitoring |
| `MeowtionIntro_slide20.svg` | MeowtionIntro | 20 | On-device health monitoring | on-device health monitoring |
| `MeowtionIntro_slide21.svg` | MeowtionIntro | 21 | A programmable platform | a programmable platform |
| `MeowtionIntro_slide23.svg` | MeowtionIntro | 23 | Not a single-purpose gadget | not a single-purpose gadget |
| `MeowtionIntro_slide24.svg` | MeowtionIntro | 24 | The dashboard | and the dashboard |
| `MeowtionIntro_slide25.svg` | MeowtionIntro | 25 | Visualised data | gives humans the visualised data to help them know when |
| `MeowtionIntro_slide26.svg` | MeowtionIntro | 26 | Know when to see a vet | to talk to a vet |

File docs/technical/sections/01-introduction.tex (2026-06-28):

\section{Introduction}
\label{sec:introduction}

\subsection{Motivation}

Cats evolved to conceal illness. A cat that feels unwell masks it for as long as it can, so by the
time a problem is obvious to an owner it is often advanced~\cite{stella2011sickness,robertson2018pain}.
The early signal is rarely a dramatic symptom; it is a quiet shift in routine. A cat that drinks
noticeably more, eats less, stops grooming, or sleeps through activity it used to enjoy is
communicating a change. No person watches their cat continuously, and day-to-day memory is a poor
baseline, so the change stays invisible.
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

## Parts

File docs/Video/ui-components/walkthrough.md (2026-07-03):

# Dashboard UI walkthrough , component by component

Isolated screenshots of each part of the owner dashboard (captured from the read-only demo, viewing
the simulated cat "Purrminator" over 23,29 Jun 2026). Each entry explains what the component is, what
it is for, and how the user interacts with it.

---

### `comp-01-cat-selection.png` , Cat Selection
**What:** A segmented switcher, shown only when the account has more than one cat.
**Purpose:** Choose which cat the whole page is about.
**Interaction:** Tap a cat. The active one fills with the brand lavender and a check; every section
below (current activity, health watch, history) re-renders for that cat.

### `comp-02-current-activity.png` , Current activity (live card)
**What:** A live status card: the on-device detected behaviour (e.g. "purring"), an online/offline
dot, whether it is detecting on-device or simulated, and battery %.
**Purpose:** An at-a-glance "what is the cat doing right now".
**Interaction:** Read-only; it auto-refreshes about every 10 seconds. During low-power rest it shows
"Resting , low power" instead of a model class.

### `comp-03-health-watch.png` , Health watch
**What:** Per-habit metrics (eating, drinking, grooming, resting) with a "% vs usual" delta, plus
warning banners and a weather note.
**Purpose:** The core health feature: compare recent days against the cat's own longer-run baseline
and flag big, lasting changes in a vet-oriented way (not a diagnosis). Weather context is shown so a
warm-spell change isn't mistaken for illness.
**Interaction:** Read-only. A warning banner appears for any habit that has moved by roughly 30% or
more versus normal.

### `comp-04-date-picker.png` + `comp-04b-date-calendar.png` , Date picker
**What:** A calendar control (closed box, and the open calendar popover).
**Purpose:** Choose the time window for the history charts , a single day or a date range. The view
derives the granularity (one day vs multiple days) from the span.
**Interaction:** Click the lavender-bordered box to open the calendar; click one day for a single day,
or two days for a range (the popover shows 23,29 selected). Both charts below update to match.

### `comp-05-activity-filters.png` , Activity filter buttons
**What:** One toggle button per behaviour, in the shared colourblind-safe palette.
**Purpose:** Show or hide activities so the small habits (eat, drink) aren't drowned out by the big
ones (resting, sleeping).
**Interaction:** Click to toggle. Filled = on, outline = off. The choice applies to both charts at
once, and the colours match across the buttons and both charts.

### `comp-06-time-per-activity.png` , Time per activity (totals)
**What:** A bar chart of total minutes per behaviour over the chosen window, biggest first.
**Purpose:** The "how much" view , where the cat's time goes.
**Interaction:** Driven by the date picker and the activity filters; hover a bar for the exact minutes.

### `comp-07-timeline.png` , When activities happened (timeline)
**What:** A rows-of-days timeline: the y-axis is the calendar day, the x-axis is time of day, and each
event is a coloured bar at the time it occurred. The x-axis spans the data's actual range.
**Purpose:** The "when" view , read the cat's daily rhythm and spot patterns at a glance.
**Interaction:** Scroll or drag to zoom the time axis; the centred "Reset view" button returns to the
full day.

### `comp-08-recent-activity.png` , Recent activity (live feed)
**What:** A list of the most recent detected events: icon, behaviour name, time, and duration, newest
first.
**Purpose:** A live feed of what the collar just logged; useful for a quick sanity check.
**Interaction:** Read-only; auto-refreshes about every 2 minutes.

### `comp-09-footer.png` , Footer (data safety + support)
**What:** A collapsible "How your data is used" disclosure, a cat-health resource link, and
report-an-issue links.
**Purpose:** Privacy transparency and a route to get help.
**Interaction:** Click the row to expand the disclosure; the links open external pages.

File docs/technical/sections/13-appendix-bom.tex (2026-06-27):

\section{Bill of materials}
\label{sec:appendix-bom}

The complete parts list for one collar and one station, plus the tools and print files. There is no
custom PCB; each device is a Seeed XIAO module in a 3D-printed shell. Source of truth:
\texttt{hardware/README.md}.

\begin{table}[ht]
  \centering
  \caption{Collar parts (one per cat).}
  \label{tab:bom-collar}
  \begin{tabularx}{\textwidth}{@{}lcX@{}}
    \toprule
    \textbf{Part} & \textbf{Qty} & \textbf{Notes} \\
    \midrule
    Seeed XIAO nRF52840 Sense & 1 & SoC with BLE; on-module IMU + PDM microphone; runs inference \\
    1S LiPo cell, 3.7\,V 100\,mAh, with protection (BMS) & 1 & Soldered to the BAT pads; protected cell required \\
    20\,mm hydrophobic PTFE filter membrane & 1 & Over the mic hole; passes sound, blocks water/dust \\
    10\,mm quick-release safety collar & 1 & Standard strap; the TPU skin mounts to it \\
    \bottomrule
  \end{tabularx}
\end{table}

\begin{table}[ht]
  \centering
  \caption{Station parts (one per spot).}
  \label{tab:bom-station}
  \begin{tabularx}{\textwidth}{@{}lcX@{}}
    \toprule
    \textbf{Part} & \textbf{Qty} & \textbf{Notes} \\
    \midrule
    Seeed XIAO ESP32-S3 & 1 & BLE central + Wi-Fi gateway \\
    USB-C cable + 5\,V supply & 1 & Mains-powered; no battery \\
    \bottomrule
  \end{tabularx}
\end{table}

\begin{table}[ht]
  \centering
  \caption{Tools, consumables, and 3D-print files.}
  \label{tab:bom-tools}
  \begin{tabularx}{\textwidth}{@{}lX@{}}
    \toprule
    \textbf{Item} & \textbf{Notes} \\
    \midrule
    USB-C cable                 & Flash and set up both boards \\
    Filament                    & PETG for the rigid shells, flexible TPU for the collar skin \\
    Water-resistant glue        & Bonds the shell halves and seals against splashes \\
    FDM 3D printer              & A standard 0.4\,mm nozzle is sufficient \\
    \texttt{front-shell.stl}    & Shared by collar and station (PETG) \\
    \texttt{collar-back-shell.stl} & Collar (PETG) \\
    \texttt{collar-silicone-skin.stl} & Collar (flexible TPU) \\
    \texttt{station-back-shell.stl} & Station (any rigid filament) \\
    \bottomrule
  \end{tabularx}
\end{table}

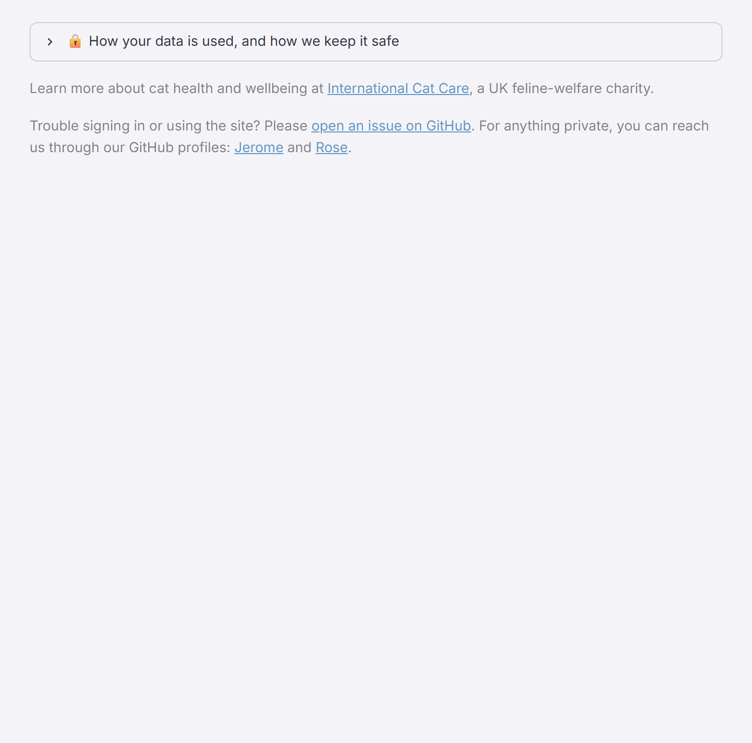
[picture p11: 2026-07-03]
docs/Video/ui-components/comp-09-footer.png

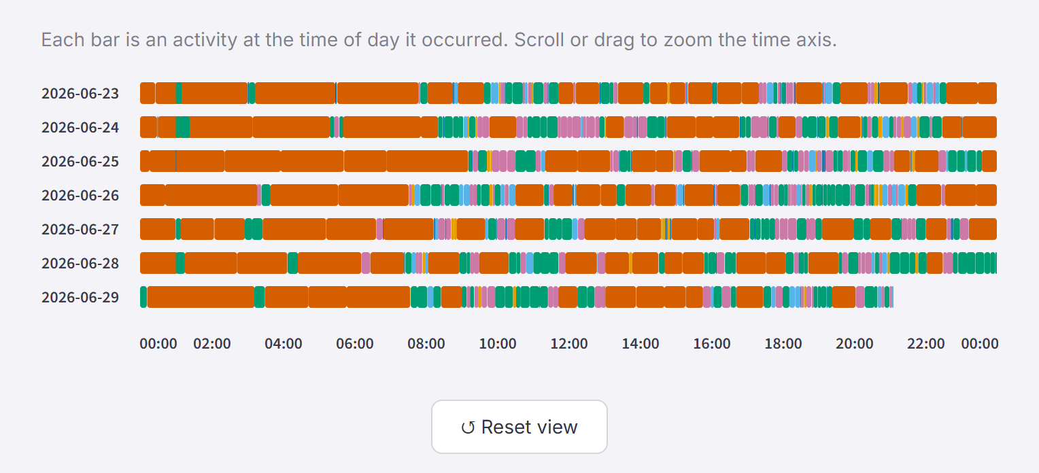
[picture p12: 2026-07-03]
docs/Video/ui-components/comp-07-timeline.png

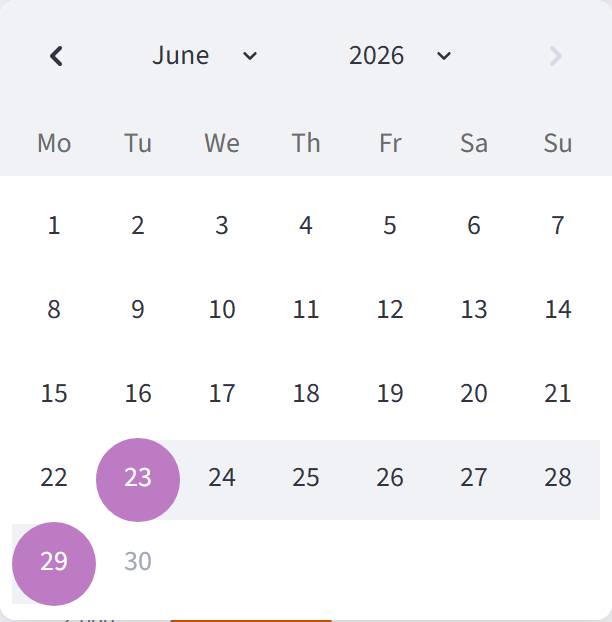
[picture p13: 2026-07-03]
docs/Video/ui-components/comp-04b-date-calendar.png

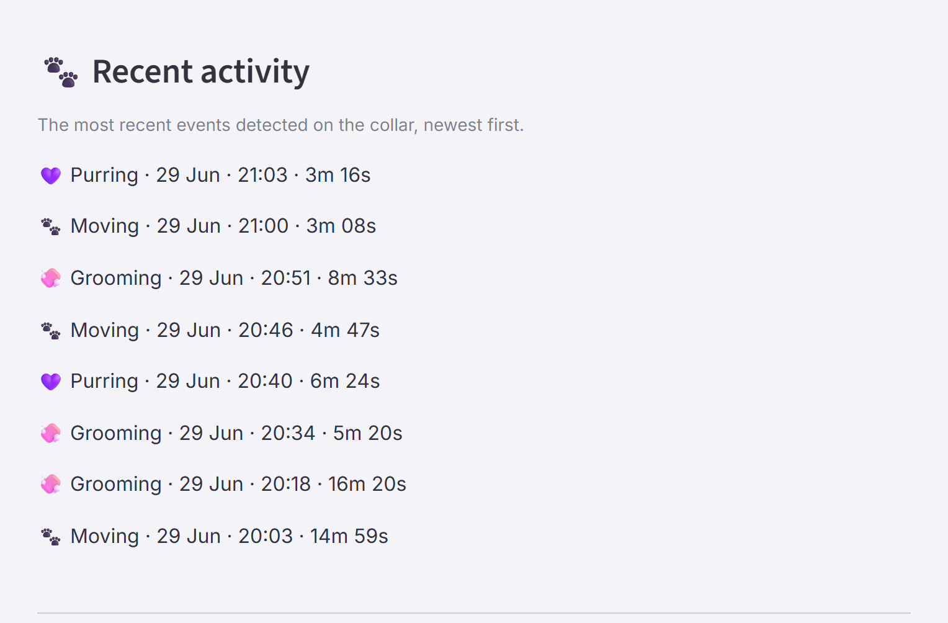
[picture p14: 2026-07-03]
docs/Video/ui-components/comp-08-recent-activity.png

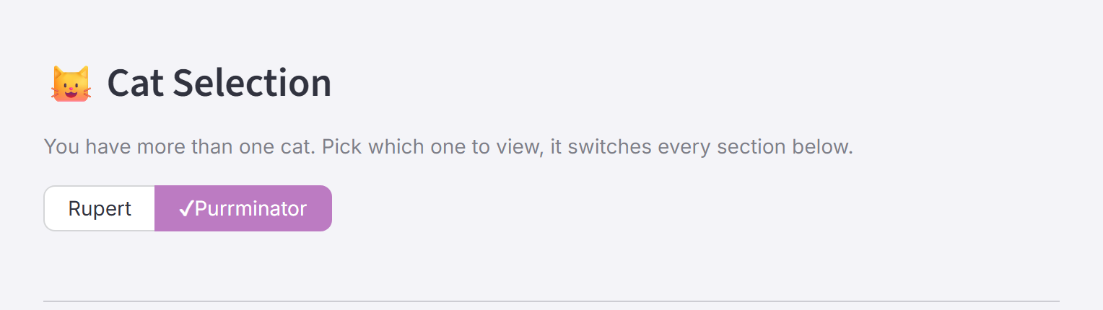
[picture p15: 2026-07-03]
docs/Video/ui-components/comp-01-cat-selection.png

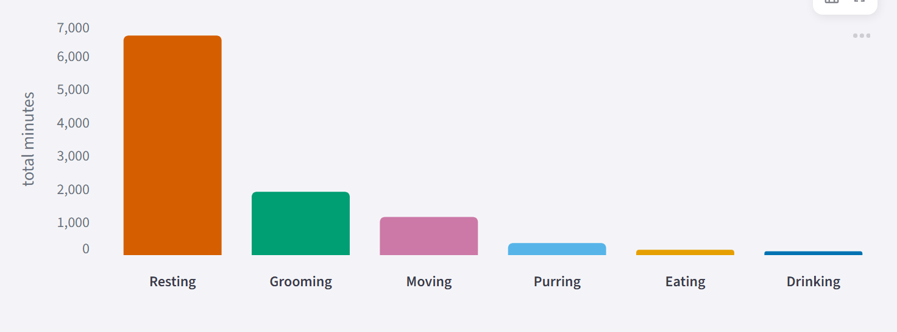
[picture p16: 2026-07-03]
docs/Video/ui-components/comp-06-time-per-activity.png

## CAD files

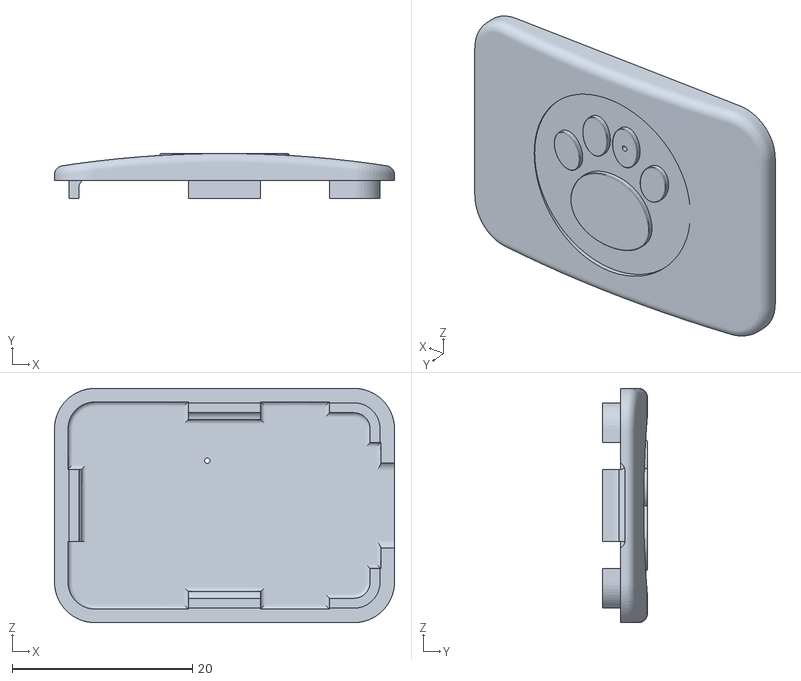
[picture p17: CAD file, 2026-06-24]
hardware/3d-files/front-shell.stl
37.7 x 5.00 x 26.0

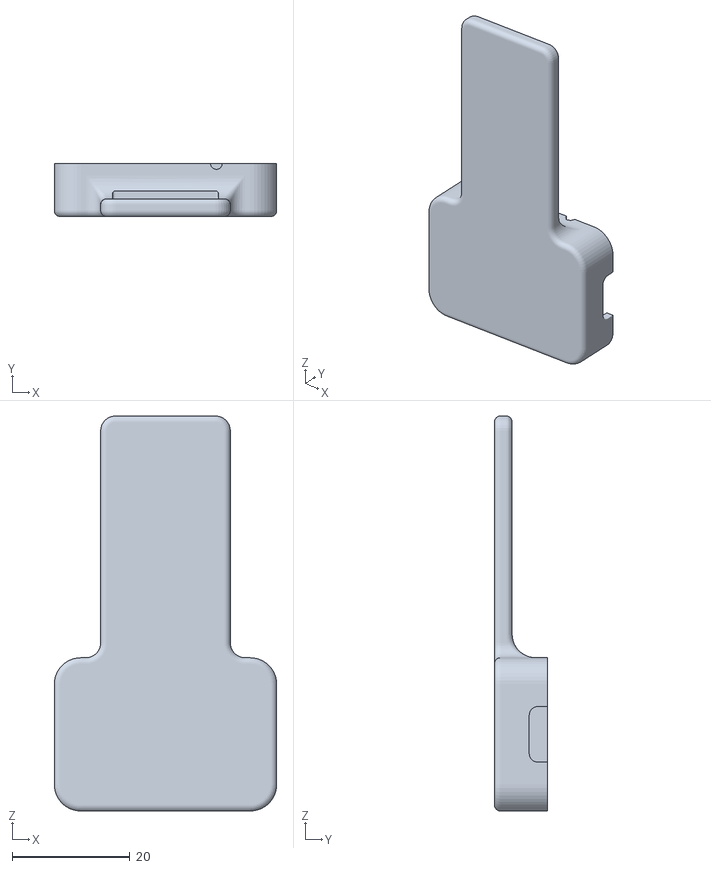
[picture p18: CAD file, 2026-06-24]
hardware/3d-files/station-back-shell.stl
37.7 x 9.00 x 67.0

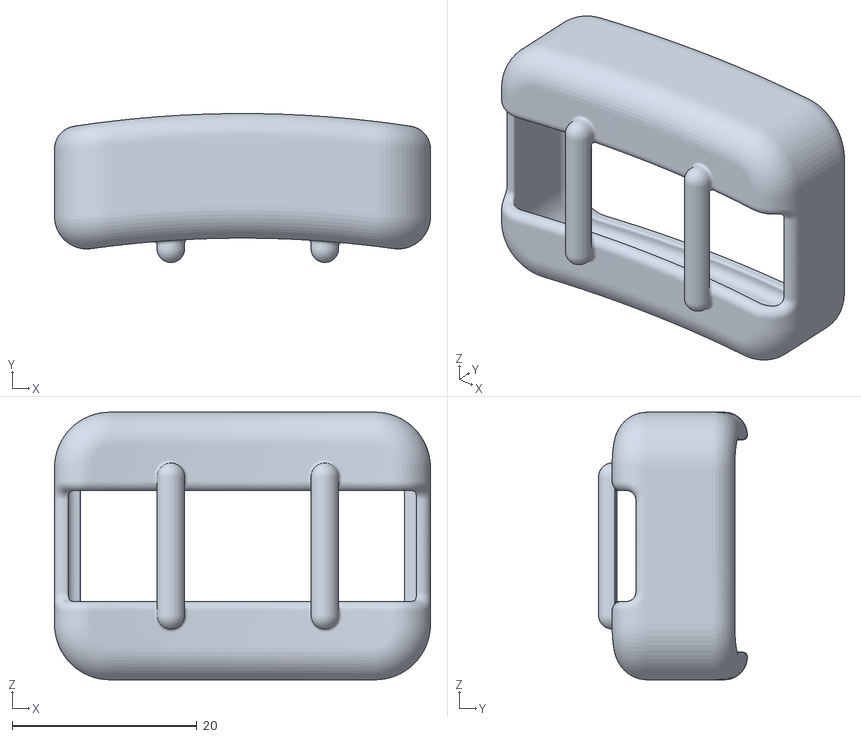
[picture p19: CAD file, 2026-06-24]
hardware/3d-files/collar-silicone-skin.stl
40.7 x 16.1 x 29.0

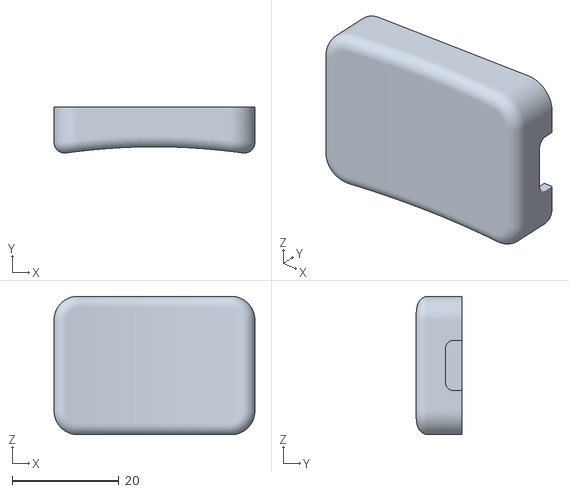
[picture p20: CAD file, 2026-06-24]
hardware/3d-files/collar-back-shell.stl
37.7 x 8.68 x 26.0

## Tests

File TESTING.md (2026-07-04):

# Testing

Automated unit tests cover the pure, high-value logic in each component. They run with
[pytest](https://pytest.org) and need no cloud credentials or hardware.

## Setup

```bash
python -m pip install -r requirements-dev.txt   # pytest (the test runner)
```

The dashboard tests also need `pandas` and the cloud-function tests need `numpy`; both are
already listed in those components' own requirements.

## Run

```bash
python -m pytest app/dashboard/tests app/firebase/functions/tests
```

## What is covered

- **`app/dashboard/tests/`** (`test_data.py`, `test_more.py`) , the dashboard data layer
  (`meowtion_dash/data.py`): raw-event to DataFrame conversion, model-label resolution by class
  index, the low-power **rest** event handling (class byte `0xFE` falls back to the `rest` type
  instead of indexing the label list), activity / date-range / weekday filtering, the time-window
  drill-down, the per-day timeline segmenting, and the health-watch recent-vs-baseline comparison.
  Malformed events (missing timestamp) are skipped.
- **`app/firebase/functions/tests/`** , the cloud function's signal and input-validation logic
  (`main.py`); the Firebase SDKs are stubbed (see `conftest.py`) so the helpers test in isolation:
  - `test_dsp.py` , per-window normalisation (the exact representation the collar must reproduce at
    inference, a core cascade-correctness property) and the overlapping-window framing with
    short-input zero-padding.
  - `test_helpers.py` , the path-segment validators (`_SAFE_ID` / `_SAFE_TS`, a security control
    against path traversal / injection) and the WAV parser.
  - `test_fuzz.py` , property / fuzz tests that throw adversarial and tens of thousands of
    seeded-random inputs at the validators and the WAV parser. Writing these caught and fixed a
    trailing-newline validation bypass and a `parse_wav` crash.

## Firmware (collar, C)

The on-device cascade logic is pure C, so it is unit-tested on the host (no Zephyr, no hardware)
under `firmware/test/`:

- **`test_activity.c`** , the rules-based activity gate (`activity.c`): motion keeps the collar
  awake, sustained stillness past the hold-off trips low-power rest, and any motion resets the timer.
- **`test_classifier.c`** , the confidence-gated cascade (`classifier.c`): the audio stage runs
  only when it is enabled, a model is present, audio exists for the cycle, and the IMU was unsure,
  and the more-confident stage wins. classifier.c's weak model hooks are overridden with scripted
  stubs.
- **`test_audio_codec.c`** , the G.711 µ-law codec (`meow_protocol.h`), swept exhaustively over the
  whole int16 domain, and the model-input representation (`audio_codec.h`), with a differential test
  proving the collar's training-clip and inference audio representations are identical samples.
  Writing this caught and fixed a µ-law `INT16_MIN` encoding bug.

Run (needs any host C compiler, e.g. gcc/clang):

```bash
make -C firmware/test check
```

## Continuous integration

`.github/workflows/test.yml` runs both the Python and the C suites on every push and pull request,
so the tests are exercised automatically even without a local C toolchain.

## Manual and on-hardware verification

The end-to-end behaviour that can't be unit-tested off-device was checked on the real hardware,
the collar (XIAO nRF52840 Sense) and the station (ESP32-S3), over USB serial, plus the
build and deploy steps. Each row was directly observed.

| # | Area | Condition / action | Expected | Result |
|---|---|---|---|---|
| 1 | Model delivery | Boot the collar with OTA'd models in flash | Both slots load | Serial: `slot 0 loaded: 23616 bytes`, `slot 1 loaded: 19640 bytes` ✓ |
| 2 | On-device inference | Collar in production mode | Real class + confidence on a full window | Serial: `production: cls=… conf=…% (win=624/624)` ✓ |
| 3 | Activity gate → rest | Hold the collar still ~60 s | Drops to low-power rest | Serial: `activity: still >= 60s , entering low-power rest`, periodic logging stops ✓ |
| 4 | Wake on motion | Move the collar while resting | Wakes and resumes classification | Serial: `activity: motion , waking after Ns rest`, production resumes ✓ |
| 5 | Rest event | Collar rests, then wakes | Station logs the span as a `rest` episode | Station serial: `relay cat_… rest` for the dormant span (steps frozen) ✓ |
| 6 | REST mapping fix | Station running updated firmware | `0xFE` shown as `rest`, not `active` | Station relay reported `rest` after reflash (was `active` before) ✓ |
| 7 | Collar build | `west build` (NCS v3.3.1) | Builds, UF2 produced | FLASH 57.7 %, RAM 86.1 %, `zephyr.uf2` written ✓ |
| 8 | Station build | `idf.py build` (ESP-IDF) | Builds, image produced | `esp32_firebase_test.bin`, 22 % partition free ✓ |
| 9 | Docs build | `build.ps1` (XeLaTeX + Biber) | Compiles, no errors | PDF produced and published ✓ |
| 10 | Backend deploy | `firebase deploy` (rules + functions) | Released to `meowtion-app` | Rules released; `upload_clip`, `train`, `simulate(_now)` updated ✓ |

These complement the automated suites above: the unit tests pin the pure logic, and this table
records the integration behaviour confirmed on hardware.

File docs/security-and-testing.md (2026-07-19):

# Security and testing evidence

This document states Meowtion's security controls and its automated testing, with the evidence for
each (source files, enforced rules, CI workflows, and badges). Everything below describes the system
as it stands.

---

## Security

Security is enforced by the backend and the rules, not by the client. The collar holds no
credentials, the station holds only a scoped, revocable token, and every read and write is checked
against per-owner rules.

### Identity and per-owner isolation
Owners authenticate with Firebase Authentication. All of an owner's data lives under
`users/<uid>/`, and the Realtime Database and Cloud Storage rules scope every read and write to the
owning account, so an owner (and that owner's devices) can reach only their own data.
**Evidence:** `app/firebase/database.rules.json`, `app/firebase/storage.rules` (deployed to project
`meowtion-app`).

### Devices use scoped tokens, not credentials
A station authenticates with a per-device token that maps to exactly one owner
(`deviceTokens/<token>/owner`); the collar holds nothing. A token grants access only to that device's
own subtree, and deleting it revokes the device with no password change and no effect on the owner's
other devices. The database rules allow an account to **claim only an unclaimed token or one it
already owns**, so a known token cannot be re-pointed to another account.
**Evidence:** the `deviceTokens` and `users/<uid>/devices/<token>` rules in
`app/firebase/database.rules.json`.

### Storage denies all direct client writes
Training clips (the only sensitive recorded data) are readable only by the owning account and are
never world-readable. Model blobs are public-read so the token-only station can fetch them for
over-the-air delivery. **No client writes to Storage at all**, uploads happen only through the
authenticated `upload_clip` function, which writes as administrator into the owner's area.
**Evidence:** `app/firebase/storage.rules` (training owner-read + `write: false`; models public-read
+ `write: false`; catch-all deny).

### Authenticated, validated clip ingest
`upload_clip` verifies the device token, which it reads from an `Authorization: Bearer` header (kept
out of URLs and request logs). The path segments it interpolates into Storage object names
(`collar`, `ts`) are constrained by regular expressions, which prevents path-traversal and injection,
and the upload body is size-capped.
**Evidence:** `app/firebase/functions/main.py`; the `_SAFE_ID` / `_SAFE_TS` regexes are unit-tested
in `app/firebase/functions/tests/test_helpers.py`.

### Privileged training is gated
Model training (`train`) is restricted to developer accounts, verified server-side from a Firebase
ID token and checked against `config/devAccounts/<uid>`.
**Evidence:** `app/firebase/functions/main.py`.

### Configuration is least-privilege
The `config` subtree is never client-writable. Reads are scoped to only what a client needs:
`config/demoOwner` is public (it backs the read-only demo) and a signed-in user may read only their
own `config/devAccounts/<uid>` flag, so the developer list cannot be enumerated.
**Evidence:** the `config` rules in `app/firebase/database.rules.json`.

### Enforced read-only demo
The public demo reads one designated account whose data the rules make world-readable but
write-locked, so the demo cannot change data or trigger any function. The read-only behaviour holds
even against a hand-crafted client because it is enforced by the rules, not hidden in the UI.
**Evidence:** the `users/<uid>` read rule keyed on `config/demoOwner`.

### Secret handling
No service-account key is present in the repository; the Cloud Functions run on their ambient service
account. Device Wi-Fi credentials are entered at runtime and never committed. The Firebase web API
key in the static front end is a public client identifier (security is enforced by Authentication and
the rules, not by hiding it). `.gitignore` guards against committing any local secret file.
**Evidence:** `.gitignore`; a scan of the tracked files finds no credentials other than the public
web API key.

### Automated security scanning
CodeQL static analysis (GitHub code scanning) runs on every push and pull request; findings surface
in the repository's Security tab.
**Evidence:** `.github/workflows/codeql.yml` and the **CodeQL** badge.

---

## Testing

Testing is split deliberately: pure logic is covered by automated unit tests run in CI, and the
integration and on-device behaviour that cannot be unit-tested is verified on the real hardware and
backend.

### Automated unit tests
80 Python unit tests and host-compiled C tests run on every push:

- **Dashboard data layer** (`app/dashboard/tests/`) , raw-event to DataFrame conversion, model-label
  resolution, the low-power-rest (`0xFE`) event handling, activity filtering, the time-window
  drill-down, and the health-watch recent-vs-baseline comparison.
- **Cloud function logic** (`app/firebase/functions/tests/`) , per-window normalisation (the exact
  representation the collar must reproduce at inference), the overlapping-window framing, the WAV
  parser, and the path-validation regexes (a security control).
- **Property / fuzz tests** (`app/firebase/functions/tests/test_fuzz.py`) , encode the invariants of
  the untrusted-input surface (the path validators and the WAV parser) and throw adversarial and
  tens of thousands of seeded-random inputs at them. Writing these caught and fixed two issues: a
  trailing newline slipping past the `^...$` path validators (now anchored with `\Z`), and `parse_wav`
  raising a raw `struct.error` on a truncated `fmt` chunk instead of `ValueError`.
- **On-device cascade (C)** (`firmware/test/`) , the rules-based activity gate (sustained stillness
  trips low-power rest; motion resets the timer) and the confidence-gated cascade (the audio stage
  runs only when enabled, present, audio exists, and the IMU was unsure; the more-confident stage
  wins).
- **Audio codec + representation (C)** (`firmware/test/test_audio_codec.c`) , the G.711 µ-law codec
  swept exhaustively over all 65,536 `int16` values, plus a differential test proving the collar's
  training wire representation and its inference representation are identical samples. Writing these
  caught and fixed a µ-law bug: `INT16_MIN` (`-32768`) encoded to near-silence because negating it as
  `int16` overflowed; the magnitude is now taken in a wider `int`.

**Evidence:** the test suites above and the green **tests** badge.

### Coverage
Line coverage of the unit-testable core (`meowtion_dash/data.py` and the pure helpers in the Cloud
Function's `main.py`) is **100%**. The Firebase request handlers, TensorFlow training, the Streamlit
UI, and the hardware-bound firmware paths are excluded from this figure and are verified by the
manual / on-hardware checks below.
**Evidence:** the **coverage** badge (Codecov) and `.coveragerc`.

### Continuous integration
Every push and pull request runs the full Python suite, the C suite, and CodeQL.
**Evidence:** `.github/workflows/test.yml`, `.github/workflows/codeql.yml`; status badges in the
README.

### Manual and on-hardware verification
The integration behaviour was confirmed directly on the collar (XIAO nRF52840 Sense) and station
(ESP32-S3) over USB serial, plus the build and deploy steps:

| # | Area | Condition | Result |
|---|---|---|---|
| 1 | Model delivery | Boot with OTA'd models in flash | Both slots load (23,616 B IMU; 19,640 B audio) |
| 2 | On-device inference | Production mode | Real class + confidence on a full window |
| 3 | Activity gate | Still ~60 s | Enters low-power rest; periodic logging stops |
| 4 | Wake on motion | Move while resting | Wakes and resumes classification |
| 5 | Rest event | Rest then wake | Station logs the span as one `rest` episode |
| 6 | Collar build | `west build` (NCS v3.3.1) | UF2 produced (FLASH 57.6 %, RAM 86.6 %) |
| 7 | Station build | `idf.py build` (ESP-IDF) | Image produced (22 % partition free) |
| 8 | Backend deploy | `firebase deploy` | Rules and functions released to `meowtion-app` |

**Evidence:** `TESTING.md` (full table and run instructions).

### Scope statement
What the automated tests deliberately do not cover, and why: the Firebase request handlers and the
TensorFlow training are integration code (verified by deploy + the table above); the Streamlit UI is
presentation; and the firmware's hardware-bound modules require the on-device checks above rather than
host unit tests. The boundary is recorded in `.coveragerc` and the `# pragma: no cover` markers.

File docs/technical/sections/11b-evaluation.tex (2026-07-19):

\section{Evaluation}
\label{sec:evaluation}

This section reports the system's measured performance: the dataset the models were trained and
evaluated on, the classification accuracy of the on-device cascade on a held-out split, the behaviour of
the gated audio confirmation stage, and the on-device resource footprint. Accuracy and confusion are
measured on a held-out test split of the collar's own recorded clips; the resource footprint is read from
the firmware build. On-hardware timing (inference latency and over-the-air transfer) and power draw are
not yet instrumented and are noted as future work (\cref{sec:future-work}).

\subsection{Dataset}

The models were trained and evaluated on labelled behaviour clips recorded from a single cat with the
collar (\cref{sec:training-pipeline}), each a 5\,s window of $\mu$-law audio paired with time-aligned
motion. Of 191 recorded clips, 155 carry a behaviour label; the remaining 36 are unlabelled and are
excluded from training and evaluation. The label set is discovered from the data rather than fixed
(\cref{sec:on-device-ai}); on this recording it is \emph{eat}, \emph{drink}, \emph{resting} and
\emph{moving}.

\begin{table}[ht]
  \centering
  \caption{Dataset summary.}
  \label{tab:dataset}
  \begin{tabularx}{\textwidth}{@{}lX@{}}
    \toprule
    \textbf{Property} & \textbf{Value} \\
    \midrule
    Cats                      & 1 \\
    Capture sessions          & 19 \\
    Clip length               & 5\,s \\
    Audio sample rate         & 8\,kHz ($\mu$-law) \\
    IMU sample rate           & 104\,Hz (6-axis) \\
    Labelled clips            & 155 (a further 36 are unlabelled and excluded) \\
    Train / test split        & 116 / 39 clips (held-out 25\,\%, stratified by class) \\
    \bottomrule
  \end{tabularx}
\end{table}

\begin{table}[ht]
  \centering
  \caption{Labelled clips per behaviour class.}
  \label{tab:dataset-classes}
  \begin{tabularx}{\textwidth}{@{}Xr@{}}
    \toprule
    \textbf{Class} & \textbf{Clips} \\
    \midrule
    Eat      & 94 \\
    Resting  & 40 \\
    Drink    & 11 \\
    Moving   & 10 \\
    \midrule
    \textbf{Total (labelled)} & 155 \\
    \bottomrule
  \end{tabularx}
\end{table}

\subsection{Classification accuracy}

The collar runs the confidence-gated cascade of \cref{sec:on-device-ai}: the IMU stage classifies every
window, and the audio stage confirms when the IMU result is uncertain (softmax confidence below the
operating threshold of 0.75). On the held-out test split the cascade reaches an overall accuracy of
\textbf{92.3\,\%} (36 of 39 clips). On this dataset the IMU stage alone reaches the same 92.3\,\%: the
gated audio stage fired but did not change the outcome (\cref{tab:confusion} and the following
subsection).

\begin{table}[ht]
  \centering
  \caption{Per-class precision / recall / F1 on the held-out split. On this data the full cascade is
           identical to the IMU stage alone, so a single set of figures is shown.}
  \label{tab:accuracy}
  \begin{tabularx}{\textwidth}{@{}X rrr@{}}
    \toprule
    \textbf{Class} & \textbf{Precision} & \textbf{Recall} & \textbf{F1} \\
    \midrule
    Eat      & 0.89 & 1.00 & 0.94 \\
    Resting  & 1.00 & 1.00 & 1.00 \\
    Drink    & 1.00 & 0.67 & 0.80 \\
    Moving   & 0.00 & 0.00 & 0.00 \\
    \midrule
    \textbf{Overall accuracy} & \multicolumn{3}{c}{92.3\,\%} \\
    \bottomrule
  \end{tabularx}
\end{table}

\begin{table}[ht]
  \centering
  \caption{Confusion matrix on the held-out split (rows = actual, columns = predicted).}
  \label{tab:confusion}
  \begin{tabular}{@{}l rrrr@{}}
    \toprule
    & \multicolumn{4}{c}{\textbf{Predicted}} \\
    \cmidrule(lr){2-5}
    \textbf{Actual} & Drink & Eat & Moving & Resting \\
    \midrule
    Drink   & 2 & 1  & 0 & 0 \\
    Eat     & 0 & 24 & 0 & 0 \\
    Moving  & 0 & 2  & 0 & 0 \\
    Resting & 0 & 0  & 0 & 10 \\
    \bottomrule
  \end{tabular}
\end{table}

\subsection{The gated audio confirmation stage}

The audio stage exists to separate behaviours that look alike to an accelerometer but differ by sound,
eating and drinking being the canonical case. On the held-out split it fired on 6 of the 39 test clips
(15\,\%), the windows where the IMU stage sat below the 0.75 confidence threshold. On this small
single-cat set it changed none of those predictions and corrected no errors, so the cascade's accuracy
equals the IMU stage's. The interpretation is not that the stage is redundant but that it was not needed
here: the IMU model was already confident and correct on the confusable cases present in this recording,
so the gated audio stage had nothing to overturn. Establishing a measured accuracy gain from the audio
stage calls for a larger and more behaviourally ambiguous dataset than this first single-cat recording,
and is left to future work (\cref{sec:future-work}). The value demonstrated here is the mechanism itself:
a second, independent sensing modality that is consulted only when the primary stage is unsure, at no
extra cost when it is confident.

\subsection{Resource footprint}

The collar is the binding resource constraint. The tensor arena is statically allocated and dominates the
RAM cost of inference; the audio window buffer and the BLE stack (now including LE Secure Connections
pairing) make up most of the rest.

\begin{table}[ht]
  \centering
  \caption{Collar resource footprint (the constraining device), read from the firmware build.}
  \label{tab:footprint}
  \begin{tabularx}{\textwidth}{@{}llX@{}}
    \toprule
    \textbf{Resource} & \textbf{Value} & \textbf{Notes} \\
    \midrule
    RAM (static)        & 226\,KiB of 256\,KiB & Static \texttt{data+bss} with inference and the encrypted
                                                 BLE link enabled (88.3\,\%); includes the shared tensor
                                                 arena. 231\,364\,B \\
    Flash (image)       & 337\,KiB             & Application image (\texttt{text+data}), excluding the
                                                 model partition (63.4\,\%). 345\,476\,B \\
    Shared tensor arena & 48\,KiB              & One arena for both stages; only one model is resident at a
                                                 time (IMU and audio flip in and out) \\
    Model storage       & 256\,KiB flash       & Two OTA slots; the interpreter reads weights directly from
                                                 this partition (XIP), with only the shared arena in RAM \\
    IMU model size      & 23\,736\,B ($\approx$23\,KiB) & int8 \texttt{.tflite}; delivered to slot~0 over
                                                 the air, not in the firmware image \\
    Audio model size    & 19\,760\,B ($\approx$19\,KiB) & int8 \texttt{.tflite}; delivered to slot~1 \\
    \bottomrule
  \end{tabularx}
\end{table}

\subsection{Testing and verification}

The system's logic is covered by automated unit tests that run in continuous integration on every change,
and the integration and on-device behaviour is verified on the hardware. The security controls and their
evidence are detailed separately (\cref{sec:security-privacy}).

\begin{itemize}[leftmargin=1.5em]
  \item \textbf{Automated unit tests.} 80 Python tests cover the dashboard data layer and the Cloud
        Function's signal logic (per-window normalisation, windowing, WAV parsing, and the path-validation
        regexes), including property and fuzz tests that hammer the untrusted-input surface. Thirteen
        host-compiled C tests cover the on-device cascade (the rules-based activity gate and the
        confidence-gated IMU/audio gating) and the $\mu$-law audio codec and model-input representation,
        the latter swept exhaustively over the whole int16 domain and checked to match the training
        representation. The full per-test inventory is listed in \cref{app:tests}.
  \item \textbf{Continuous integration.} Every push and pull request runs the Python and C test suites.
  \item \textbf{On-hardware verification.} Model load-from-flash, on-device classification, the activity
        gate's rest/wake cycle, the encrypted collar-to-station link, and the build and backend-deploy
        steps were each confirmed directly on the collar and station.
\end{itemize}

\subsection{Limitations and outlook}

The evaluation is a first, single-cat, within-subject result and should be read as such. The dataset is
small (155 labelled clips) and imbalanced: eat dominates (94 clips) while moving and drink have only 10
and 11 clips, so their per-class figures are unreliable, moving in particular scoring zero on a two-clip
test slice. The held-out split is a single stratified 25\,\% partition, not cross-validated. On-device
inference latency, over-the-air transfer time and power draw are not yet instrumented on the hardware; the
resource footprint above is the measured on-device figure available now.

The progress is nonetheless encouraging, and the results point clearly at what to do next. A 92.3\,\%
held-out accuracy from the IMU stage, learned from barely 150 clips of a single cat, is a solid baseline,
and the confidence-gated cascade behaves exactly as designed: the audio stage engages precisely on the
low-confidence windows and stays out of the way otherwise. That it shows no accuracy gain \emph{yet} is a
data gap, not a design flaw. With only 11 drink clips the audio model cannot yet learn the eat/drink
acoustic distinction it exists to make, so it has nothing to contribute to the very cases it was built
for. The clearest single lever is therefore more clips of the sparse classes, drink above all: with a
balanced set the audio confirmation stage has a good prospect of delivering the disambiguation the
architecture is built around, and the strong IMU baseline suggests the overall system will hold up well as
the label set and the cat population grow. Scaling the recording to more cats and behaviours, and
instrumenting the on-hardware timing and power measurements, is set out as future work
(\cref{sec:future-work}).

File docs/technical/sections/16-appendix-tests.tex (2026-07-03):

\section{Automated test inventory}
\label{app:tests}

% Identifiers/literals contain underscores; \detokenize renders them literally without manual escaping
% and avoids the \path clash with TikZ used elsewhere in this document.
\providecommand{\tn}[1]{\texttt{\detokenize{#1}}}

% A filled-in test-case form (IEEE-829 style). One per automated test.
% #1 ID  #2 Title  #3 Component  #4 Type  #5 Preconditions  #6 Input/data  #7 Procedure  #8 Expected  #9 Status
\newcommand{\testcase}[9]{%
  \par\smallskip\noindent
  \begingroup\footnotesize
  \arrayrulecolor{mwline}\setlength{\arrayrulewidth}{0.4pt}\renewcommand{\arraystretch}{1.25}%
  \begin{tabularx}{\textwidth}{|>{\bfseries\color{mwink}}p{3.0cm}|X|}
    \hline
    \rowcolor{mwlav!10}\multicolumn{2}{|@{\hspace{6pt}}l|}{%
      {\bfseries\color{mwlavd}Test case #1}\hfill{\color{mwmut}#4}}\\
    \hline
    Title & #2\\\hline
    Component & #3\\\hline
    Preconditions & #5\\\hline
    Input / test data & #6\\\hline
    Procedure & #7\\\hline
    Expected result & #8\\\hline
    Actual result & As expected\\\hline
    Status & \textbf{#9}\\\hline
  \end{tabularx}%
  \endgroup\smallskip
}

This appendix is the test-case specification for the project's automated tests: one filled form per
test, recording its scenario, inputs, expected result and status. The suites run in continuous
integration on every push and pull request (\cref{sec:evaluation}). As of the run on 2026-07-01,
\textbf{all 93 tests pass}: \textbf{80} Python tests (run with \texttt{pytest}) and \textbf{13}
host-compiled C tests for the on-device cascade and the audio codec. Line coverage of the unit-testable core
(\tn{meowtion_dash/data.py} and the Cloud Function's \tn{main.py}) is \textbf{100\,\%}. Parametrised
tests are recorded as a single form whose input field lists every case. ``Actual result: as expected''
denotes the assertions held when the suite last ran.

\subsection{Firmware tests (C, host-compiled)}

Compiled and run on the host from \tn{firmware/test} (no Zephyr, no hardware). The classifier tests
link strong overrides of the model hooks (declared \texttt{weak} in \tn{classifier.c}) and count
audio-stage invocations, so every gating branch is checked.

\testcase{ACT-01}{Motion keeps the collar awake}{Activity gate , \tn{activity.c}}{Unit test (host C)}
{\tn{activity_reset()} called; step \tn{dt}=2\,s.}
{100 consecutive readings at peak motion \tn{ACT_STILL_MG}+50 (above the stillness threshold).}
{Call \tn{activity_should_rest(peak, 2)} for each reading.}
{Every call returns ``do not rest'' , motion never drops the collar to low-power rest.}{Pass}

\testcase{ACT-02}{Sustained stillness trips rest}{Activity gate , \tn{activity.c}}{Unit test (host C)}
{\tn{activity_reset()} called; step \tn{dt}=2\,s.}
{Still readings (peak 0) every 2\,s, spanning the hold-off \tn{ACT_REST_HOLDOFF_S}.}
{Call \tn{activity_should_rest(0, 2)} repeatedly across the hold-off.}
{Returns ``no rest'' for every step before the hold-off, then ``rest'' once stillness is sustained past it.}{Pass}

\testcase{ACT-03}{Motion resets the still-timer}{Activity gate , \tn{activity.c}}{Unit test (host C)}
{\tn{activity_reset()} called; still-timer advanced to just before the hold-off.}
{One reading at the threshold \tn{ACT_STILL_MG}, then a still reading.}
{Call \tn{activity_should_rest(ACT_STILL_MG, 2)} then \tn{activity_should_rest(0, 2)}.}
{Does not rest immediately , the motion reset the timer, so a full hold-off is required again.}{Pass}

\testcase{CLF-01}{Confident IMU skips audio}{Cascade , \tn{classifier.c}}{Unit test (host C)}
{\tn{conf_threshold}=0.75; audio confirmation enabled; audio model present.}
{IMU = (class 2, confidence 0.90); audio = (5, 0.99).}
{Call \tn{clf_classify()} for the cycle; count audio invocations.}
{Audio stage not run (0 calls); result class = 2 (the confident IMU result).}{Pass}

\testcase{CLF-02}{Unsure IMU consults audio}{Cascade , \tn{classifier.c}}{Unit test (host C)}
{\tn{conf_threshold}=0.75; audio confirmation enabled; audio model present.}
{IMU = (2, 0.40) below threshold; audio = (5, 0.95).}
{Call \tn{clf_classify()} for the cycle; count audio invocations.}
{Audio run exactly once; result class = 5 (the more-confident audio result).}{Pass}

\testcase{CLF-03}{Audio kept only when more confident}{Cascade , \tn{classifier.c}}{Unit test (host C)}
{\tn{conf_threshold}=0.75; audio confirmation enabled; audio model present.}
{IMU = (2, 0.40); audio = (5, 0.30) , less confident than the IMU.}
{Call \tn{clf_classify()} for the cycle; count audio invocations.}
{Audio run once but discarded; result class = 2 (the IMU result is kept).}{Pass}

\testcase{CLF-04}{Disabled confirmation never runs audio}{Cascade , \tn{classifier.c}}{Unit test (host C)}
{\tn{conf_threshold}=0.75; audio confirmation \emph{disabled}; audio model present.}
{IMU = (2, 0.40) below threshold; audio = (5, 0.95).}
{Call \tn{clf_classify()} for the cycle; count audio invocations.}
{Audio stage never runs (0 calls); result class = 2.}{Pass}

\testcase{CLF-05}{No audio buffer skips audio}{Cascade , \tn{classifier.c}}{Unit test (host C)}
{\tn{conf_threshold}=0.75; audio confirmation enabled; no PCM buffer this cycle.}
{IMU = (2, 0.40) below threshold; PCM = NULL (the production IMU-only path).}
{Call \tn{clf_classify(NULL, NULL, 0)}; count audio invocations.}
{Audio stage skipped (0 calls); result class = 2.}{Pass}

\testcase{CLF-06}{No audio model skips audio}{Cascade , \tn{classifier.c}}{Unit test (host C)}
{\tn{conf_threshold}=0.75; audio confirmation enabled; no audio model present.}
{IMU = (2, 0.40) below threshold; audio model absent.}
{Call \tn{clf_classify()} for the cycle; count audio invocations.}
{Audio stage skipped (0 calls); result class = 2.}{Pass}

\subsection{Audio codec and representation tests (C, host-compiled)}

From \tn{firmware/test/test_audio_codec.c}, over the header-only \texttt{G.711} µ-law codec
(\tn{meow_protocol.h}) and the model-input transform (\tn{audio_codec.h}). The codec invariants are
swept \emph{exhaustively} over the whole int16 domain (only 65\,536 values); the transform is fuzzed
over seeded-random windows. Writing them caught and fixed a codec bug, pinned in ACO-02 below.

\testcase{ACO-01}{Codec byte round-trip is consistent}{µ-law codec , \tn{meow_protocol.h}}{Property/fuzz (host C)}
{None.}{All 256 µ-law bytes.}
{For each byte \tn{b} whose \tn{ulaw_decode(b)} is non-zero, check \tn{ulaw_encode(ulaw_decode(b))} equals \tn{b}.}
{Holds for every byte. The two zero codes \texttt{0x7F} (-0) and \texttt{0xFF} (+0) alias to \texttt{+0} on re-encode and are exempt (standard G.711).}{Pass}

\testcase{ACO-02}{Codec preserves the sign of a non-zero sample}{µ-law codec , \tn{meow_protocol.h}}{Property/fuzz (host C)}
{None.}{Every int16 of magnitude $\geq 256$ (exhaustive).}
{Check \tn{ulaw_decode(ulaw_encode(s))} keeps the sign of \tn{s} and is non-zero.}
{Holds for all. Writing this caught \tn{INT16_MIN} ($-32768$) encoding to near-silence , negating it as int16 overflowed back to $-32768$; fixed by taking the magnitude in a wider \tn{int}.}{Pass}

\testcase{ACO-03}{Model-input transform: length and per-sample round-trip}{Audio representation , \tn{audio_codec.h}}{Property/fuzz (host C)}
{None.}{4\,000 seeded-random 16\,kHz windows and output caps.}
{Call \tn{audio_to_model_pcm}; check the length is \texttt{floor(in/2)} clamped to the cap and each output equals the µ-law round-trip of the pairwise-averaged pair.}
{Holds for every window.}{Pass}

\testcase{ACO-04}{Training wire representation equals inference representation}{Audio representation , \tn{audio_codec.h}}{Differential (host C)}
{None.}{4\,000 seeded-random 16\,kHz windows.}
{Compare \tn{audio_to_model_pcm} (inference) against the training path (decimate 16$\to$8\,kHz, \tn{ulaw_encode}, then the station's \tn{ulaw_decode}).}
{Identical samples , the collar trains and infers on the same representation, so there is no train/inference mismatch.}{Pass}

\subsection{Cloud Function tests (Python)}

From \tn{app/firebase/functions/tests}; the Firebase SDKs are stubbed in \tn{conftest.py}.
\tn{test_dsp.py} pins the exact representation the model trains on (and the collar reproduces at
inference); the \tn{test_helpers.py} path-validation forms are security tests.

\testcase{DSP-01}{Normalisation is zero-mean and bounded}{DSP , \tn{main.py}}{Unit test (pytest)}
{Firebase SDKs stubbed.}{One channel \texttt{[1,2,3]}.}{Call \tn{per_window_norm(x)}.}
{Output mean is 0 to within \texttt{1e-5}; all values lie within \texttt{[-1,1]}.}{Pass}

\testcase{DSP-02}{Normalisation matches the reference formula}{DSP , \tn{main.py}}{Unit test (pytest)}
{Firebase SDKs stubbed.}{\texttt{[0,10]}.}{Call \tn{per_window_norm(x)}.}
{Output equals \texttt{[-1,1]} exactly (mean 5 removed, then divided by max-abs 5).}{Pass}

\testcase{DSP-03}{Channels normalised independently}{DSP , \tn{main.py}}{Unit test (pytest)}
{Firebase SDKs stubbed.}{Two channels \texttt{[[0,100],[4,104]]}.}{Call \tn{per_window_norm(x)}.}
{Each channel's mean is 0 independently (channels are not pooled).}{Pass}

\testcase{DSP-04}{Short input padded to one window}{DSP , \tn{main.py}}{Unit test (pytest)}
{Firebase SDKs stubbed.}{3$\times$2 array; \tn{win}=5, \tn{hop}=2.}{Call \tn{windows(arr, win, hop)}.}
{Exactly one window of shape \texttt{(5,2)}; the last two rows are zero-padded.}{Pass}

\testcase{DSP-05}{Window slides with the hop}{DSP , \tn{main.py}}{Unit test (pytest)}
{Firebase SDKs stubbed.}{\tn{arange(10)} reshaped \texttt{(10,1)}; \tn{win}=4, \tn{hop}=3.}{Call \tn{windows(arr, win, hop)}.}
{Three windows starting at indices 0,\,3,\,6; each shape \texttt{(4,1)}.}{Pass}

\testcase{DSP-06}{Dataset windows IMU clips}{DSP , \tn{main.py}}{Unit test (pytest)}
{\tn{LABELS}=[\tn{eat},\tn{drink}].}{One IMU clip labelled \tn{drink}.}{Call \tn{build_dataset([clip], "imu")}.}
{\tn{X} shape \texttt{(1, IMU\_WIN, IMU\_AXES)}; \tn{y}=[1] (the label index).}{Pass}

\testcase{DSP-07}{Dataset windows audio clips}{DSP , \tn{main.py}}{Unit test (pytest)}
{\tn{LABELS}=[\tn{eat},\tn{drink}].}{One audio clip labelled \tn{eat}.}{Call \tn{build_dataset([clip], "audio")}.}
{\tn{X} shape \texttt{(1, AUDIO\_WIN, 1)}; \tn{y}=[0].}{Pass}

\testcase{DSP-08}{Empty IMU clip skipped}{DSP , \tn{main.py}}{Unit test (pytest)}
{\tn{LABELS}=[\tn{eat}].}{A clip with a zero-length IMU array.}{Call \tn{build_dataset([clip], "imu")}.}
{No windows produced (\tn{len(X)}=0) , empty clips never reach training.}{Pass}

\testcase{VAL-01}{Valid ids accepted}{Path validation (security) , \tn{main.py}}{Unit test (pytest)}
{Firebase SDKs stubbed.}{4 inputs: \tn{cat_64582d}, \tn{abc-123_XYZ}, \tn{A}, \tn{0}.}
{Match each against \tn{_SAFE_ID}.}{All four are accepted.}{Pass}

\testcase{VAL-02}{Traversal and separators rejected}{Path validation (security) , \tn{main.py}}{Unit test (pytest)}
{Firebase SDKs stubbed.}{10 inputs: \tn{../etc}, \tn{a/b}, \tn{a..b/}, \tn{a.b}, \tn{a b}, \tn{a;b}, empty, \tn{a/../b}, \tn{..}, \texttt{a\textbackslash b}.}
{Match each against \tn{_SAFE_ID}.}{All ten are rejected (no path can escape the owner's prefix).}{Pass}

\testcase{VAL-03}{Numeric timestamp accepted}{Path validation (security) , \tn{main.py}}{Unit test (pytest)}
{Firebase SDKs stubbed.}{\tn{1719600000000} (all digits).}{Match against \tn{_SAFE_TS}.}
{Accepted.}{Pass}

\testcase{VAL-04}{Non-numeric timestamps rejected}{Path validation (security) , \tn{main.py}}{Unit test (pytest)}
{Firebase SDKs stubbed.}{7 inputs: \tn{12a}, \tn{-1}, \tn{1.0}, \tn{../1}, empty, \tn{1 2}, \tn{0x10}.}
{Match each against \tn{_SAFE_TS}.}{All seven are rejected.}{Pass}

\testcase{WAV-01}{WAV parser round-trips samples}{WAV parsing , \tn{main.py}}{Unit test (pytest)}
{Firebase SDKs stubbed.}{An 8\,kHz mono 16-bit WAV of \texttt{[0,1,-1,32767,-32768]}.}{Call \tn{parse_wav(buf)}.}
{Returns rate 8000 and exactly those samples (including the int16 extremes).}{Pass}

\testcase{WAV-02}{Sample rate read from header}{WAV parsing , \tn{main.py}}{Unit test (pytest)}
{Firebase SDKs stubbed.}{A 16\,kHz WAV.}{Call \tn{parse_wav(buf)}.}
{Parsed rate = 16000 (read from the \texttt{fmt} chunk, not assumed).}{Pass}

\testcase{WAV-03}{Non-WAV input rejected}{WAV parsing , \tn{main.py}}{Unit test (pytest)}
{Firebase SDKs stubbed.}{Non-RIFF bytes.}{Call \tn{parse_wav(buf)}.}
{Raises \tn{ValueError}.}{Pass}

\testcase{WAV-04}{Missing data chunk rejected}{WAV parsing , \tn{main.py}}{Unit test (pytest)}
{Firebase SDKs stubbed.}{A WAV with a \texttt{fmt} chunk but no \texttt{data} chunk.}{Call \tn{parse_wav(buf)}.}
{Raises \tn{ValueError}.}{Pass}

\subsection{Property and fuzz tests (Python)}

From \tn{app/firebase/functions/tests/test_fuzz.py}, over the untrusted-input surface , the path
validators and the WAV parser, which take fully attacker-controlled values. Each form encodes an
\emph{invariant} and throws both targeted adversarial inputs and tens of thousands of seeded-random
inputs at it (stdlib \tn{random}; no external fuzzing engine, so they run in ordinary CI). Writing
them surfaced and fixed two issues, both pinned below: the id/timestamp validators accepted a trailing
newline (Python's \texttt{\$} also matches just before a newline, so the end is now anchored with
\tn{\Z}); and \tn{parse_wav} raised a raw \tn{struct.error} on a truncated \texttt{fmt} chunk instead
of \tn{ValueError}.

\testcase{FUZ-01}{Trailing terminators rejected by the id validator}{Path validation (security) , \tn{main.py}}{Property/fuzz (pytest)}
{Firebase SDKs stubbed.}{Valid ids suffixed with a trailing newline, carriage return, or NUL byte (7 cases).}
{Match each against \tn{_SAFE_ID}.}{All rejected: the end is anchored with \tn{\Z}, not \texttt{\$}, so a trailing newline cannot ride into the Storage path.}{Pass}

\testcase{FUZ-02}{Trailing terminators rejected by the timestamp validator}{Path validation (security) , \tn{main.py}}{Property/fuzz (pytest)}
{Firebase SDKs stubbed.}{Numeric timestamps suffixed with a trailing newline, CR, or NUL (4 cases).}
{Match each against \tn{_SAFE_TS}.}{All rejected.}{Pass}

\testcase{FUZ-03}{Accepted ids contain only the allowed charset}{Path validation (security) , \tn{main.py}}{Property/fuzz (pytest)}
{Firebase SDKs stubbed.}{40\,000 seeded-random strings from the allowed set plus tricky characters (newline, CR, NUL, dot, slash, backslash, space).}
{For every string \tn{_SAFE_ID} accepts, check each character is in \texttt{[A-Za-z0-9\_-]}.}
{No accepted string contains a disallowed character.}{Pass}

\testcase{FUZ-04}{Accepted timestamps contain only digits}{Path validation (security) , \tn{main.py}}{Property/fuzz (pytest)}
{Firebase SDKs stubbed.}{40\,000 seeded-random strings from digits plus tricky and letter characters.}
{For every string \tn{_SAFE_TS} accepts, check each character is a digit.}
{No accepted string contains a non-digit.}{Pass}

\testcase{FUZ-05}{Truncated fmt chunk fails cleanly}{WAV parsing , \tn{main.py}}{Property/fuzz (pytest)}
{Firebase SDKs stubbed.}{A WAV whose \texttt{fmt} chunk header declares a body the buffer does not contain.}
{Call \tn{parse_wav(buf)}.}{Raises \tn{ValueError}, not a raw \tn{struct.error} (the sample-rate read is bounds-checked).}{Pass}

\testcase{FUZ-06}{Parser survives arbitrary bytes}{WAV parsing , \tn{main.py}}{Property/fuzz (pytest)}
{Firebase SDKs stubbed.}{6\,000 seeded-random byte buffers, half prefixed with a valid RIFF/WAVE header.}
{Call \tn{parse_wav} on each.}{Every call returns \texttt{(int16 samples, rate)} or raises \tn{ValueError} , never another exception, never a hang.}{Pass}

\testcase{FUZ-07}{Parser survives adversarial chunk sizes}{WAV parsing , \tn{main.py}}{Property/fuzz (pytest)}
{Firebase SDKs stubbed.}{6\,000 syntactically-plausible chunk streams with adversarial sizes (zero, odd, and up to $2^{31}$).}
{Call \tn{parse_wav} on each.}{Returns cleanly or raises \tn{ValueError} , the size arithmetic never overruns a read.}{Pass}
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

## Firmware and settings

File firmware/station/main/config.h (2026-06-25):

#pragma once
/*
 * PUBLIC project config , NOT secrets. The device does not log in to Firebase at all:
 * it writes to /users/{owner}/devices/{token}/... over HTTPS, and the database rule
 * allows it because the token (provisioned over USB into NVS) is registered to that owner.
 *
 * WiFi, owner, token, and weather location are all provisioned over USB serial. There is
 * no API key here.
 */
#include <stddef.h>
#include <stdint.h>
#include <stdbool.h>

#define DB_URL   "https://meowtion-app-default-rtdb.europe-west1.firebasedatabase.app"

/* Authenticated clip ingest. Audio/IMU clips are POSTed to the upload_clip Cloud Function
 * (it validates the device token and writes them into the owner's training area), so the
 * station never touches Firebase Storage directly. */
#define UPLOAD_CLIP_URL "https://europe-west1-meowtion-app.cloudfunctions.net/upload_clip"

#define DEFAULT_LAT 50.8     /* fallback if the browser didn't pass a location */
#define DEFAULT_LON -0.1

/* Provisioned identity (defined in config.c). */
extern char   g_ssid[64], g_pass[64], g_owner[64], g_token[96], g_name[64];
extern char   g_device_id[16];     /* MAC hex , just for the picker handshake */
extern double g_lat, g_lon;

/* shared helpers */
void    setstr(char *dst, size_t cap, const char *src);
int64_t now_ms(void);

/* Per-station "last model version pushed to the collar" (OTA gate). Stored in the same "meow" NVS
 * namespace; defaults to 0 when never written. ota.c compares this against RTDB models/<owner>/ver. */
uint32_t nvs_get_model_ver(void);
void     nvs_set_model_ver(uint32_t ver);

/* NVS persistence + USB-serial provisioning */
bool nvs_load(void);
int  serial_read_line(char *buf, int cap, int timeout_ms);
bool try_provision(const char *line);
void provision_mode(void);

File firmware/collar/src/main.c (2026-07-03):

/*
 * Meowtion collar firmware (Zephyr / nRF Connect SDK, XIAO nRF52840 Sense).
 *
 * The collar is BLE-only: it senses on the cat and runs ONE connectable advertisement carrying a
 * small telemetry packet plus a custom audio service. A station (ESP32) reads the telemetry and,
 * when it connects + subscribes, the collar streams paired audio + IMU for training-data capture.
 * The collar never touches WiFi/internet , that keeps it tiny and low-power.
 *
 * Module split:
 *   ble.c        advertising, identity, the audio GATT service, notify
 *   audio.c      PDM mic capture -> 8 kHz µ-law
 *   streaming.c  the decoupled reader/sender threads that assemble + send frames
 *   battery.c    1S LiPo charge via the onboard divider
 *   imu.c        LSM6DS3TR-C continuous sampler   (unchanged)
 *   classifier.c the confidence-gated action cascade (weak stubs until a model lands; unchanged)
 *
 * Telemetry packet (manufacturer-specific AD data, 8 bytes). The version byte [2] tells the station
 * which of two contracts is in force:
 *
 *   version = 1  SIMULATED (pre-training fallback, update_telemetry_sim() below):
 *     [2]=1  [3] state(0..5)  [4] activity(0..100)  [5..6] steps LE  [7] battery
 *
 *   version = 2  REAL ON-DEVICE CLASSIFICATION (production.c, runs once a model is present):
 *     [2]=2  [3] class INDEX (0..N-1) into the model's label table, or 0xFF = UNKNOWN/low-confidence
 *     [4] confidence 0..100 (round(confidence*100))  [5..6] steps LE  [7] battery
 *
 * The collar's BLE address identifies which collar it is (no id needed in the payload).
 *
 * PRODUCTION vs SIMULATED is chosen each cycle by production_active() (a trained IMU model is linked
 * AND we are not in a training-capture stream). With no model the simulated state machine runs and
 * version stays 1; once a model lands, real IMU classification drives the telemetry and version is 2.
 */
#include <zephyr/kernel.h>
#include <zephyr/bluetooth/bluetooth.h>
#include <zephyr/random/random.h>
#include <zephyr/logging/log.h>
#include <zephyr/usb/usb_device.h>
#include <zephyr/drivers/uart.h>

#include "ble.h"
#include "audio.h"
#include "battery.h"
#include "imu.h"
#include "classifier.h"
#include "activity.h"
#include "production.h"
#include "ota.h"

LOG_MODULE_REGISTER(collar, LOG_LEVEL_INF);

/* state: 0 sleep, 1 rest, 2 active, 3 walk, 4 play, 5 groom */
static uint8_t  g_state = 1;
static uint16_t g_steps = 0;
static uint8_t  g_battery = 96;
static int64_t  g_state_until = 0;       /* uptime (ms) at which the current state ends */

/* per-state dwell range (seconds) and a typical activity level (0..100). A cat holds a
 * behaviour for a realistic spell instead of flickering every packet, so the station relays
 * sensible episodes. (Placeholder until real IMU classification.) */
static const uint16_t DUR_MIN[6] = {  60, 40, 20, 20, 20, 20 };
static const uint16_t DUR_MAX[6] = { 180, 120, 60, 40, 50, 40 };
static const uint8_t  ACT[6]     = {   2, 12, 55, 45, 80, 30 };

/* SIMULATED telemetry (version = 1) , the pre-training fallback. Runs only while no trained model is
 * present; once a model lands, production_update_telemetry() (version = 2) replaces it. Real
 * IMU-based classification lives in production.c / classifier.c. Left intact and unchanged. */
static void update_telemetry_sim(void)
{
    int64_t now = k_uptime_get();

    /* hold each behaviour for a realistic dwell, then transition to a new one */
    if (now >= g_state_until) {
        g_state = sys_rand32_get() % 6;
        uint32_t secs = DUR_MIN[g_state] + (sys_rand32_get() % (DUR_MAX[g_state] - DUR_MIN[g_state] + 1));
        g_state_until = now + (int64_t)secs * 1000;
    }

    if (g_state >= 2 && g_state <= 4) {              /* moving: steps accrue */
        g_steps += 1 + sys_rand32_get() % 4;
    }
    g_battery = read_battery();          /* real pack charge (rises on USB charge) */

    int act = (int)ACT[g_state] + ((int)(sys_rand32_get() % 11) - 5);   /* jitter +/-5 */
    if (act < 0) act = 0; else if (act > 100) act = 100;

    uint8_t *mfg = ble_mfg_data();
    mfg[2] = 1;                          /* version 1 = simulated (pre-training fallback) */
    mfg[3] = g_state;
    mfg[4] = (uint8_t)act;
    mfg[5] = g_steps & 0xFF;
    mfg[6] = (g_steps >> 8) & 0xFF;
    mfg[7] = g_battery;
}

/* Telemetry class byte (version=2 packet) meaning "collar is in low-power rest". Distinct from a
 * model class index (0..N-1) and from 0xFF=UNKNOWN; the station maps it to a "rest" episode so the
 * whole dormant span becomes one rest event. */
#define TELEM_REST  0xFE

/* Cascade TIER 0 , low-power rest. Entered from the production branch once the rules-based activity
 * gate (activity.c) sees sustained stillness. Stops the 104 Hz stream + inference, drops the IMU to
 * a low-power watch ODR, slows the radio, and advertises a REST beacon so the station opens a rest
 * episode. Polls the IMU slowly for motion; on motion it restores active operation and returns, and
 * the next production cycle re-advertises a real class so the station closes the rest episode (the
 * rest event covering the dormant span). Leaves early if a central connects or a capture starts so
 * the normal loop can service it. */
static void enter_low_power_rest(void)
{
    LOG_INF("activity: still >= %us , entering low-power rest", ACT_REST_HOLDOFF_S);

    production_yield();              /* stop the 104 Hz stream + drop the inference window */
    imu_set_lowpower(true);         /* low-power watch ODR */
    ble_set_adv_slow(true);         /* slow the radio */

    /* Advertise the REST beacon (version=2, class=REST) so the station logs the rest episode. */
    uint8_t *mfg = ble_mfg_data();
    mfg[2] = 2;
    mfg[3] = TELEM_REST;
    mfg[4] = 0;
    mfg[7] = read_battery();
    if (!ble_is_connected()) { ble_start_adv(); ble_update_adv(); }

    const int64_t t0 = k_uptime_get();
    int64_t last_beacon = t0;
    while (1) {
        if (ble_is_connected() || ble_streaming_enabled()) break;   /* let the main loop service it */
        if (imu_motion_mg() >= ACT_WAKE_MG) break;                  /* motion , wake */
        int64_t now = k_uptime_get();
        if (now - last_beacon >= 12000) {       /* refresh < the station's 30 s stale window */
            mfg[7] = read_battery();
            ble_start_adv();
            ble_update_adv();
            last_beacon = now;
        }
        k_sleep(K_MSEC(500));                   /* SoC idles between polls */
    }

    LOG_INF("activity: motion , waking after %llus rest",
            (unsigned long long)((k_uptime_get() - t0) / 1000));
    imu_set_lowpower(false);        /* restore the classification sampling rate */
    ble_set_adv_slow(false);        /* restore the fast advertising interval */
    activity_reset();
    /* the next loop iteration restarts production (imu_stream_start) and resumes classification. */
}

int main(void)
{
    /* Bring up USB so the CDC ACM console (the COM port) works, then wait up to ~3 s for a
     * serial terminal to attach (DTR) so boot logs aren't lost. We never block forever , the
     * collar must advertise even with no USB host attached. */
    if (usb_enable(NULL) == 0) {
        const struct device *con = DEVICE_DT_GET(DT_CHOSEN(zephyr_console));
        uint32_t dtr = 0;
        for (int i = 0; i < 30 && !dtr; i++) {
            uart_line_ctrl_get(con, UART_LINE_CTRL_DTR, &dtr);
            k_sleep(K_MSEC(100));
        }
    }

    battery_init();
    audio_mic_init();
    clf_init();                  /* action-classifier cascade (runs model-free until models land) */
    ota_load_stored_models();    /* re-load any previously-OTA'd model from flash so it's live now */
    if (!imu_init())             /* LSM6DS3TR-C; sampled alongside each clip + fed to the cascade */
        LOG_ERR("IMU init FAILED , clips will upload audio-only (no paired motion data)");

    int err = bt_enable(NULL);
    if (err) {
        LOG_ERR("bt_enable failed (%d)", err);
        return 0;
    }

    ble_compute_id();
    ble_start_adv();             /* connectable: telemetry beacon + audio service */
    LOG_INF("collar advertising (connectable), id=%s", ble_id());

    while (1) {
        /* Finish loading any OTA-delivered model here, on the main thread's big stack (clf_set is too
         * stack-heavy for the BLE-RX callback). No-op when nothing is pending. */
        ota_service_loads();

        /* Two clear branches. PRODUCTION (a trained IMU model is linked AND we're not in a capture
         * stream): run real on-device classification on a rolling IMU window and emit the version=2
         * packet. Otherwise fall back to the SIMULATED state machine (version=1). During a capture
         * stream we do neither , streaming.c owns the IMU + mic to build training clips. */
        if (production_active()) {
            production_update_telemetry();
            /* Cascade tier 0: if the cat has been still past the hold-off, drop to low-power rest
             * until motion returns. This is the main battery lever , no 104 Hz sampling, no
             * inference, and a slow radio while the cat is resting. */
            if (activity_should_rest(production_peak_mg(), 2)) {
                enter_low_power_rest();
            }
        } else {
            production_yield();          /* release our IMU ownership so capture/re-entry is clean */
            update_telemetry_sim();
        }

        /* Ensure we're advertising whenever not connected. This self-heals the re-advertise after
         * a capture disconnects (restarting adv from the disconnect callback is unreliable), so the
         * station can reconnect for the next clip. While connected, advertising is off , skip it. */
        if (!ble_is_connected()) {
            ble_start_adv();
            ble_update_adv();
        }
        /* Identity banner the dashboard reads over USB serial to register this collar. */
        printk("MEOW> collar id=%s\n", ble_id());
        /* Log the values that are actually live this cycle: the simulated globals are only updated in
         * the simulated branch, so logging them in production mode would print frozen numbers. */
        if (production_active()) {
            LOG_INF("production: peak=%umg stream=%d",
                    production_peak_mg(), ble_streaming_enabled());
        } else {
            LOG_INF("sim: state=%u steps=%u batt=%u stream=%d",
                    g_state, g_steps, g_battery, ble_streaming_enabled());
        }
        k_sleep(K_SECONDS(2));   /* TODO: wake-on-motion deep sleep for battery life */
    }
    return 0;
}

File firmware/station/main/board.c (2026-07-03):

/*
 * board.c , board power sensing.
 *
 * Sole job: tell the rest of the firmware whether the station is running on USB or a battery,
 * and (when on battery) the rough charge percent. Everything else about the hardware lives in
 * its own module.
 */
#include "board.h"

#include "driver/gpio.h"
#include "esp_adc/adc_oneshot.h"

/* ---------------- power source (battery wired to A0, or USB) ----------------
 * A 2x220 ohm divider on A0 (GPIO1 / ADC1_CH0) reads Vbat/2 when a battery is wired in.
 * With the internal pulldown enabled, an unwired (USB-only) pin floats low instead. So a
 * real voltage => battery present (and a %); near-zero => USB powered.
 * NOTE: the 500 mV threshold and pulldown behaviour should be confirmed on the real board. */
static adc_oneshot_unit_handle_t s_adc = NULL;

const char *g_power = "usb";
int g_batt_pct = -1;            /* -1 when USB / no battery */

/* A0 reads VBAT through a 2x220k divider. 1S LiPo percent is a crude LINEAR map (not a real
 * state-of-charge curve): 3.0 V = 0%, 4.2 V = 100%. */
#define BATT_MV_EMPTY     3000
#define BATT_MV_FULL      4200
#define BATT_ADC_SAMPLES  8

void power_init(void)
{
    gpio_set_pull_mode(GPIO_NUM_1, GPIO_PULLDOWN_ONLY);   /* A0 floats low when no battery divider */
    adc_oneshot_unit_init_cfg_t u = { .unit_id = ADC_UNIT_1 };
    if (adc_oneshot_new_unit(&u, &s_adc) != ESP_OK) { s_adc = NULL; return; }
    adc_oneshot_chan_cfg_t c = { .atten = ADC_ATTEN_DB_12, .bitwidth = ADC_BITWIDTH_DEFAULT };
    adc_oneshot_config_channel(s_adc, ADC_CHANNEL_0, &c);   /* ADC1_CH0 = GPIO1 = A0 */
}

void read_power(void)
{
    if (!s_adc) { g_power = "usb"; g_batt_pct = -1; return; }
    int sum = 0, raw = 0, ok = 0;
    for (int i = 0; i < BATT_ADC_SAMPLES; i++)
        if (adc_oneshot_read(s_adc, ADC_CHANNEL_0, &raw) == ESP_OK) { sum += raw; ok++; }
    if (ok == 0) { g_power = "usb"; g_batt_pct = -1; return; }    /* every read failed */
    int mv = (sum / ok) * 3300 / 4095;           /* average only successful reads; ~0-3.3 V at 12 dB atten */
    if (mv < 500) { g_power = "usb"; g_batt_pct = -1; return; }   /* floats low => no battery wired */
    int vbat = mv * 2;                            /* undo the 2x220 divider */
    int pct = (vbat - BATT_MV_EMPTY) * 100 / (BATT_MV_FULL - BATT_MV_EMPTY);   /* percent (linear) */
    g_power = "battery";
    g_batt_pct = pct < 0 ? 0 : (pct > 100 ? 100 : pct);
}

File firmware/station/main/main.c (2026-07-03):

/*
 * Meowtion station firmware (ESP-IDF, Seeed XIAO ESP32-S3).
 *
 * The Meowtion base station: it relays the cat collar's BLE telemetry to the owner's Firebase
 * account and captures short audio + IMU clips for training. No Firebase login , WiFi, owner, and
 * a per-device TOKEN are provisioned over USB serial and stored in NVS. The device writes to
 * /users/{owner}/devices/{token}/... over HTTPS; the database rule allows it because the token is
 * registered to that owner (deviceTokens[token].owner == owner). Delete the token to revoke.
 *
 * On boot it loads NVS (or waits for serial provisioning), joins WiFi, syncs time, marks itself
 * online, then runs a ~1 s loop: relay registered collars (current + proximity), service audio
 * capture, and poll weather.
 *
 * This file owns only orchestration; each subsystem lives in its own module:
 *   config  , provisioned creds + NVS + USB-serial provisioning + shared helpers
 *   board   , power source (USB vs battery)
 *   wifi    , STA bring-up + time sync
 *   cloud   , the Firebase RTDB / HTTP layer (the only HTTP)
 *   weather , Open-Meteo feed
 *   ble     , the whole NimBLE collar subsystem (scan/relay + audio capture)
 *
 * Provisioning JSON (sent by the dashboard's Connect form, or paste into the monitor):
 *   {"ssid":"..","pass":"..","owner":"<uid>","token":"<random>","name":"..","lat":50.8,"lon":-0.1}
 * Re-provision with `idf.py erase-flash`.
 */
#include <stdio.h>
#include "freertos/FreeRTOS.h"
#include "freertos/task.h"
#include "freertos/event_groups.h"
#include "nvs_flash.h"
#include "esp_log.h"
#include "esp_mac.h"
#include "esp_system.h"
#include "driver/usb_serial_jtag.h"

#include "config.h"
#include "board.h"
#include "wifi.h"
#include "weather.h"
#include "ble.h"
#include "ota.h"

static const char *TAG = "meowtion";

void app_main(void)
{
    esp_err_t ret = nvs_flash_init();
    if (ret == ESP_ERR_NVS_NO_FREE_PAGES || ret == ESP_ERR_NVS_NEW_VERSION_FOUND) {
        ESP_ERROR_CHECK(nvs_flash_erase());
        ret = nvs_flash_init();
    }
    ESP_ERROR_CHECK(ret);

    usb_serial_jtag_driver_config_t ujc = USB_SERIAL_JTAG_DRIVER_CONFIG_DEFAULT();
    usb_serial_jtag_driver_install(&ujc);

    uint8_t mac[6];
    esp_read_mac(mac, ESP_MAC_WIFI_STA);
    snprintf(g_device_id, sizeof g_device_id, "%02x%02x%02x%02x%02x%02x",
             mac[0], mac[1], mac[2], mac[3], mac[4], mac[5]);
    printf("MEOW> meowtion id=%s boot\n", g_device_id);

    if (!nvs_load()) provision_mode();
    ESP_LOGI(TAG, "owner %s, token %.8s..., \"%s\"", g_owner, g_token, g_name);

    if (!wifi_init_sta()) {
        /* Couldn't get on WiFi (likely wrong credentials saved at pairing). Don't block forever:
         * the driver keeps retrying in the background, and meanwhile we listen for a fresh
         * provisioning line over USB so the dashboard can fix the credentials without an
         * erase-flash. (wifi_init_sta already ran once , do NOT call it again, that re-inits the
         * driver and aborts.) */
        ESP_LOGW(TAG, "WiFi connect failed , awaiting re-provisioning over serial");
        char pline[512];
        while (!(xEventGroupGetBits(s_wifi_eg) & WIFI_CONNECTED_BIT)) {
            printf("MEOW> meowtion id=%s awaiting-provisioning\n", g_device_id);
            if (serial_read_line(pline, sizeof pline, 5000) > 0 && try_provision(pline)) {
                ESP_LOGW(TAG, "re-provisioned , restarting");
                vTaskDelay(pdMS_TO_TICKS(300));
                esp_restart();
            }
        }
        ESP_LOGI(TAG, "WiFi recovered");
    }
    wait_for_time();
    power_init();
    ble_start();                 /* scan for collars; only registered ones are relayed */
    ble_fetch_allow();           /* load the registered-collar allow-list (the gate) */
    ble_fetch_config();          /* load the capture-range settings (rssiThreshold, dwellMs) */

    /* Presence is derived from freshness (the station's lastSeen heartbeat + each cat's
     * current.ts), so a device that loses power just stops heartbeating and reads offline. */

    char line[512];
    int tick = 0;
    bool was_capturing = false;
    /* The loop ticks every ~1 s so ble_service() drains BUF_READY clips promptly: a 5 s clip
     * completes every 5 s, and with only two ping-pong buffers, a slow uploader would let both fill
     * and force the frame parser to drop audio. The Firebase-write-heavy calls (heartbeat, relay,
     * publish, config/allow/weather polls) are gated on tick multiples so their cadence is unchanged
     * , crucially they do NOT run on every pass during a capture, which would steal upload time from
     * ble_service and drop clips. */
    while (1) {
        if (tick % 10 == 0) {
            /* Allow re-pairing from the dashboard at any time: announce ourselves, and if a new
             * provisioning line arrives (after the device was disconnected and re-added), adopt
             * the new token and restart cleanly. */
            printf("MEOW> meowtion id=%s\n", g_device_id);
            if (serial_read_line(line, sizeof line, 200) > 0 && try_provision(line)) {
                ESP_LOGW(TAG, "re-provisioned , restarting");
                vTaskDelay(pdMS_TO_TICKS(300));
                esp_restart();
            }
            ble_heartbeat();          /* station presence + power + registered-collar count */
            ble_relay();              /* relay registered collars (current + proximity/rssi, the gate) */
            ble_publish_seen();       /* advertise heard-but-unregistered collars for the dashboard */
            ble_fetch_config();       /* poll capture toggle + range (~10 s) */
        }
        if (tick % 60 == 0) ble_fetch_allow();                            /* refresh allow-list (~60 s) */
        if (ble_allowed_count() > 0 && tick % 900 == 0) poll_weather();   /* data only once a collar is registered */

        /* The instant a capture ends, refresh presence + state ONCE, before ble_service drains the last
         * clips (which blocks this loop for several seconds). A capture stalls the tick-gated heartbeat,
         * so without this the dashboard's post-record "saving" phase can briefly read the station
         * offline (lastSeen past its 35 s window) or the collar not connected. Firing on the
         * capture->idle edge keeps lastSeen fresh entering the save, without adding writes mid-capture. */
        bool capturing = ble_capture_active();
        if (was_capturing && !capturing) { ble_heartbeat(); ble_relay(); }
        was_capturing = capturing;

        ble_service();   /* serviced every tick (~1 s) so the clip buffers never back up */
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

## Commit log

2026-06-24 Add hardware build guide, 3D print files and assembly images
    [collar-back-shell.stl, collar-silicone-skin.stl, front-shell.stl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]
2026-06-24 Show a loading state while the cookie component mounts
    CookieManager.get_all() returns None on first render before it reports the browser
    cookies. Treat None as still-loading (show Loading...) instead of flashing the
    not-signed-in screen; an empty dict means genuinely signed out.
2026-06-24 Replace auto-redirect with a sign-in gate
    The meta-refresh auto-redirect loops/hangs on Streamlit Community Cloud (a known issue;
    component-iframe scripts are also sandbox-blocked from top navigation). Logged-out visitors
    now get a Please sign in screen with a link button instead - reliable, and still keeps them
    off the dashboard.
2026-06-24 Dashboard: plain-text email, Manage devices + Log out buttons
    - Email shown as plain text (zero-width space defeats markdown's mailto auto-link)
    - Log out button: deletes the session cookie via CookieManager and gates the signed-out
    view on a session flag (CookieManager get_all caches, so a soft rerun alone misses it)
    - manage devices is now a button next to Log out, via st.link_button
2026-06-25 Dashboard: Log out returns to login page; align top-bar buttons
    - Log out is a same-tab link to account.html?logout=1; account.js handles it by signing out
    of Firebase and clearing the cookie, then shows the login form (account.js also clears the
    cookie whenever Firebase has no user)
    - top bar rendered as one flexbox row so the caption and the Manage devices / Log out buttons
    align (st.columns + markdown anchors did not line up)
    - account.html: no-cache metas + a script version so the updated logout JS reaches users
    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
2026-06-25 Add root README and dashboard/firebase docs
    - root README: product/health story, architecture diagram, on-device AI + any-behaviour,
    repo map, getting-started links, tech stack, privacy/security
    - app/dashboard/README: dev-console walkthrough; fixed stale login description (CookieManager
    + sign-in gate + logout-to-login) and removed broken docs links
    - app/firebase/README: backend setup, deploy + gotchas, the two functions, security, config nodes
2026-06-25 Refactor station firmware into modules; fix .gitignore
    - station: split the 1179-line main.c into config/board/wifi/cloud/weather/ble/main
    modules; main.c is orchestration-only and the NimBLE subsystem is encapsulated behind
    ble_service(). Builds clean via idf.py.
    - retarget to meowtion-app; switch clip upload to the authenticated upload_clip Cloud
    Function (records the Storage path, not a public URL) - completes the Storage hardening.
    - remove the debug counters and the stale SimCat comment.
    - .gitignore: gitignore has no inline comments, so secrets.h / serviceAccount*.json /
    .streamlit/secrets.toml were not actually being ignored (now fixed); also ignore the
    firmware build artifa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
    [board.c, config.h]
2026-06-25 Refactor collar firmware into modules; add firmware READMEs
    - collar: split main.c into ble / audio / streaming / battery + main; imu, classifier and
    audio_codec kept as-is. main.c is orchestration-only; builds clean on NCS v3.3.1. The
    simulated telemetry is clearly marked as a Phase-1 scaffold pending the trained classifier.
    - READMEs: firmware/ (index), collar/ (rewritten for the connectable + streaming modular
    build), station/ (new) - each documents its modules, build, and flash steps.
2026-06-25 Add on-device inference, BLE OTA model delivery, and production classification
    Collar: TensorFlow Lite Micro inference with runtime-loaded models (model_loader.h, tflm_classifier.cpp), a models_storage flash partition, and a BLE OTA service (ota.c) that receives a .tflite, stag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
    Station: downloads trained models from Storage and pushes them to the collar over the shared meow_ota.h protocol when the model version inc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
2026-06-25 Wire model delivery and live detection into cloud and dashboard
    train: mirror the new model version into each station's device config so the token-auth station (which cannot read users/<uid>/models) can gate its OTA push on it.
    dashboard: map the collar's reported class index to the trained model's labels and show live on-device detections (telemetry v2), falling back to the simulated state for v1.
2026-06-25 station: resume scanning after an OTA push so relay + later pushes recover
    The OTA push cancels scanning to connect but handles its own disconnect via a separate GAP callback, so unlike the capture path it never restarted the observer. After one push the station went deaf: 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
2026-06-25 collar: make OTA-delivered models actually load and run on-device
    Fixes found bringing the on-device classifier up on hardware:
    - Op resolver: register EXPAND_DIMS / SQUEEZE (+ shape ops). Keras Conv1D lowers to CONV_2D wrapped in these, so AllocateTensors failed with 'Didn't find op for builtin opcode EXPAND_DIMS'.
    - Stack: TFLM AllocateTensors/Invoke overflowed the ~2 KB default main stack and faulted the collar; give main 16 KB.
    - Defer the model load off the BLE-RX callback (small stack) onto the main thread via ota_service_loads(); the callback only commits the CRC-verified bytes to flash.
    [main.c]
2026-06-25 dev page: add a read-only demo mode (dev.html?demo=1)
    Loads the config/demoOwner account's data without login and disables every write/action: guards the auth listener and all write handlers (train, mode/capture/force toggles, save-config, add-action, d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
2026-06-26 ui: correct brand lavender to #bc7bc2 and enlarge the circle paw logo
    Use the actual brand lavender (188,123,194) for the accent/logo/theme, and make the paw a big dark print that nearly fills the circle (was tiny), matching the reference.
2026-06-26 ui: use exact CAD paw outline for logo; transparent blended activity charts
    Replace the hand-drawn paw with the real paw geometry from the CAD sketch (Sketch28.dxf), converted from its B-spline outlines to SVG paths and scaled to fill the lavender badge. Charts now render transparent so they blend with the page instead of a clashing white panel.
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2026-06-26 fix(dashboard): logout from dashboard now actually signs out
    The dashboard Log out link goes to account.html?logout=1, which called signOut() during initial page load. That raced Firebase's persistence restore, which signed the user back in, so logout just landed you on the account/devices page still logged in. Defer the sign-out into onAuthStateChanged so it runs after auth state is restored. Bump account.js cache-buster to v=2.
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2026-06-26 docs: add complete LaTeX technical documentation
    Multi-file XeLaTeX + Biber technical reference under docs/technical/: preamble (packages/style/metadata), branded title page, and 12 numbered section files covering hardware, both firmwares, on-device AI, the training pipeline, cloud backend, dashboard, protocols, security, and future work. Builds via build.ps1 (no Perl/latexmk) to a git-ignored build/ folder. Adds VS Code task buttons (LaTeX build/quick/view/clean) and recommends actboy168.tasks; extends .gitignore for LaTeX aux files. Verified: compiles clean to a 15-page PDF with resolved bibliography and cross-references.
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2026-06-26 dev console: replace manual capture toggle with live-label action buttons
    Swap the 'Manual capture (ignore range)' on/off switch for a row of buttons built from the user's action set. Press what the cat is doing now; it turns on captureForce (ignore-range), records for the chosen length (default 30s), auto-labels every clip that arrives during the window with that action, tags them with a session id for later grouping, then auto-stops and turns capture off. Robust to upload lag (labels by new-clip arrival + a start-time guard, plus a 15s grace after stop) and to clock skew. Adds a leftover-force safety indicator with Stop. No firmware change. Bumps dev.js cache-buster to v=4.
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2026-06-26 dev console: centre the X in the full-screen close button
    Flex-centre the glyph and zero the button padding/line-height so the X sits in the middle of the circle. Bumps dev.css cache-buster to v=17.
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2026-06-26 dashboard: Day/Week/Month is a drill-down window, not an aggregation bucket
    Reworked: the radio picks the x-axis SPAN (one Day/Week/Month) and a selectbox picks WHICH specific window; the chart then shows just that window , x by hour for a Day, by date for a Week/Month. New helpers: period_options (windows to pick from), filter_to_window (keep one window), over_time (bucket the x-axis). bar() gains a time_format arg (hours vs dates). Tutorial steps updated to match.
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2026-06-26 dashboard: fix repeated x labels + thin bars; taller chart; hide-activity control
    The over-time bars used a continuous temporal axis, so it drew thin bars and printed the date at every auto-tick (e.g. '22 Jun' x4). Bin the x-axis by time unit (yearmonthdate for Week/Month, yearmonthdatehours for Day) so each bucket gets one wide band and one label. Make the chart taller (height 380) and add an activity multiselect , deselect Sleep/Resting (which dominate the minutes) to actually see eat/drink. stacked_bar now takes time_unit + height instead of a bare temporal flag.
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2026-06-26 sim: real-time continuous timeline + every-15-min schedule; show sim collar as live
    Replace the fixed daily schedule with a continuous, time-weighted activity timeline (the cat is always IN an activity, transitioning by per-hour probabilities), so events are random but in realistic periods and the timeline grows in real time. Deterministic per day, so re-runs/top-ups never duplicate. current_activity() drives the live state to whatever the cat is doing now; the function runs every 15 minutes and refreshes it. Dashboard shows a simulated collar as '🟢 simulated' so it reads as live.
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2026-06-27 Rewrite technical documentation: architecture/data-flow section, transparent logo title page, accurate firmware/protocol details
    Replace the opaque banner with a transparent paw logo (rendered from logo.svg) plus a typeset wordmark on the title page.
    Deep rewrite of all 12 sections grounded in the READMEs and source: new System architecture and data flow section with the four end-to-end flows; corrected firmware module tables, flash map, telemetry packet, clip frame + mu-law, and OTA protocol to match meow_protocol.h / meow_ota.h; documented the demo simulator, weather context, health analytics, and live/history fetch split. Builds clean (24 pages, no overfull boxes, refs resolved).
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2026-06-27 Add expanded-clip labelling screenshot; fix orphaned requirements subsection headings
    Embed the expanded-clip view (audio waveform + movement/rotation traces + trim controls) in the UI walkthrough, captured from a signed-in account. Add lead-in text to the functional and non-functional requirements subsections so their headings are not left empty when the tables float.
2026-06-27 Reframe technical doc as a working system with marked data placeholders
    Rewrite the Evaluation section as a results section (dataset, accuracy, audio-stage benefit, footprint, latency, power/battery, OTA) with clearly-marked red placeholders for the measurements to be filled in. Remove the simulated-until-model-loaded caveats in On-device AI and Collar firmware so telemetry reads as live classifier output. Add a model-architecture placeholder and the confidence-threshold slot. Trim now-done future-work items. Fix the XIP/'executed in place' mischaracterisation (TFLM interprets the model from flash; only the arena is in RAM). No fabricated numbers; every figure is a placeholder.
2026-06-28 Restructure technical docs into parts; add front matter, evaluation, glossary, and feline-health citations
    Reorganise into part-level chapters with an acknowledgements page and front-matter glossary. Tighten prose throughout, convert orphaning float tables to non-floating, add UI walkthrough and evaluation sections, and remove build/flash and fixed-bug aside subsections. Cite feline-medicine literature (Stella 2011, Robertson 2018, Bennett 2012, Yamazaki 2020) for the motivation claims.
2026-06-28 docs: fill technical-doc placeholders and fix flow-diagram arrow directions
    - Add closed-loop training figure; fill confidence threshold (06, 07)
    - Fill per-stage architecture table and resource footprint (model sizes,
    RAM/flash) from firmware/build (06, 11b)
    - Correct data-flow arrows: reverse RTDB->Dashboard read; make
    Station<->Storage, Station<->Collar, front-door<->dashboard, and topology
    Collar<->Station / Station<->Cloud bidirectional (02, 08, 09)
    - Add mwbiedge style; rebuild published PDF
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2026-06-28 security: harden rules, token handling, and dashboard auth; update docs
    - RTDB rules: prevent deviceTokens owner-overwrite (token hijack); scope the
    config subtree to demoOwner (public) and a user's own devAccounts flag, so the
    developer list cannot be enumerated.
    - upload_clip: read the device token from an Authorization: Bearer header (with a
    query fallback) instead of the URL, and reject oversized uploads (413).
    - station: send the device token in the Authorization header.
    - dashboard: HTML-escape the email claim before rendering.
    - docs: reflect the upload_clip header, the scoped config reads, and runtime
    Wi-Fi credentials (08, 11, 14).
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2026-06-29 fix(dashboard): clamp date-picker default into the data range (fixes out-of-range crash)
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2026-06-29 fix(dashboard): choose x-axis granularity by span length so a single-day range is hourly
2026-06-29 fix(dashboard): single-day chart x-axis spans the full 24 hours
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2026-06-29 dashboard: add a reset-view button to the multi-day timeline so you can zoom back out to the full day
2026-06-29 dashboard: make date selection obvious with a clear prompt and quick-pick shortcut buttons
2026-06-29 dashboard: style the date box so it clearly reads as clickable, drop the shortcut buttons
2026-06-29 dashboard: make the timeline x-axis span the data's actual time range, not a fixed 24h
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2026-06-29 dashboard: style the Reset view button for dark mode (scoped to its key)
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2026-06-29 cleanup: remove dead dashboard chart helpers, fix button-loop readability and stale comments, firmware correctness (production log, overflow-safe magnitude, battery defines, wav/state guards)
    [battery.c, board.c, main.c]
2026-06-29 dashboard polish: use --line token for the wave-lane border; build the IMU legend from IMU_COLORS to prevent colour drift
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2026-06-29 docs: filled test-case forms appendix, fill-in evaluation tables, corrected future-work (multi-cat/idle)
2026-06-30 fix(station): stop dev view false-alarming during the post-record save
    Recording an action then letting it save briefly showed "Collar not
    connected" and then "Station offline" in the dashboard, even with the
    collar right next to the station. Root causes, found from the station
    serial:
    - ble_publish_dev() gated its write on `heard`, but a collar stops
    advertising while it's connected for audio capture, so `heard` goes
    false mid-capture. The else branch then hard-wrote state "idle",
    clobbering the "recording" state. Now it writes whatever the state is
    whenever it isn't idle.
    - A finished capture proves the collar is reachable, so seed the
    last-heard time on disconnect and hold a sh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
    [main.c]
2026-06-30 fix(dashboard): allow recording when the station is relaying the collar
    The record gate said "collar not connected" while the station card clearly
    showed the collar with battery. recordReadiness() keyed only off the
    proximity badge (dev.state != "idle"), but a resting collar advertises
    slowly so that badge dips to "idle" between adverts even while telemetry
    keeps relaying. Now the gate also accepts a freshly relayed collar
    (cats/{id}/current), the same signal that drives the "Collar battery" stat,
    so the record panel and the device card agree.
    Also align the station's dev proximity freshness window to the relay's
    COLLAR_STALE_MS (was 15 s) so the on-card badge is likewise less twitchy
    for a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
2026-07-01 Fix stale docs and document the shared-arena / audio-confirm design
    - README firmware step no longer says "coming soon"; link both firmware READMEs
    - Correct the Python test count (57 -> 62) in security-and-testing
    - List simulator.py / weather.py / activity.c / production.c / ota.c and the
    four Cloud Functions where the READMEs and technical reference omitted them
    - Technical reference: single shared tensor arena (one model resident at a
    time), the simulate_now request, and refreshed collar footprint numbers
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2026-07-01 station+dashboard: no events during training, fix range latch, seed threshold
    - Station suppresses activity events while a capture/training session is
    engaged, so deliberately recorded actions don't land in the live history.
    - Fix the proximity latch: the post-capture grace kept a far collar pinned
    "in range" (each capture re-stamped the grace, re-triggering capture). The
    grace now only bridges the advert re-acquisition gap when the collar isn't
    currently heard; a live RSSI reading always wins.
    - Dev console seeds the capture threshold/dwell from the range card when a
    station never had them set, so the card owns the value instead of the station
    falling back to a hidden firmware d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
2026-07-01 station: make cats/current the single source for proximity, fix capture latch
    Write each collar's proximity + rssi into its own cats/{id}/current record and
    drop the separate /dev node, so the dashboard reads presence, signal and battery
    from one place instead of fusing two sources that could disagree. Each collar
    carries its own smoothed rssi and dwell, so a multi-collar station attributes
    readings to the right cat, and "recording" follows the actually-captured collar
    (g_cap_id) rather than whichever advertised last.
    Recompute the capture gate every tick from the live near-collar signal, driven
    by the real rssi rather than the post-capture display grace, and require a fresh
    advert since th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
    [main.c]
2026-07-01 dashboard: read presence/signal from cats/current, fail safe on unknown proximity
    Proximity now comes only from cats/{id}/current.proximity (the station's single
    source); the dev console no longer fuses a separate /dev node, which is what let
    the badge and the signal disagree. Pick the most-engaged collar and read its
    signal and battery from that same record. Any unknown or missing proximity value
    collapses to "away", so the badge never renders blank and the record gate never
    opens on a value it does not understand.
2026-07-01 docs: document the single-source current record; rework future work
    Schema and cloud-backend sections describe current carrying rssi + proximity as
    the one live-state source for both the owner dashboard and the dev console.
    Remove the "neither" class future-work item and the stale known-limitation that
    claimed the model misclassifies an idle cat, since the rules-based activity gate
    parks a resting cat before the classifier runs. Rework the future-work section
    into a product-first roadmap led by the health-insight analytics.
2026-07-01 functions: fuzz the upload path validators + WAV parser, fix two issues they found
    Add property/fuzz tests over the untrusted-input surface (test_fuzz.py): they
    encode each control's invariant and throw targeted adversarial inputs plus tens
    of thousands of seeded-random inputs at it (stdlib random, no new dependency).
    Writing them surfaced and fixed two issues:
    * _SAFE_ID / _SAFE_TS accepted a trailing newline, since Python's $ matches
    just before a trailing newline, so "abc\n" could ride into the Storage path.
    Anchor the end with \Z instead.
    * parse_wav raised a raw struct.error on a truncated fmt chunk instead of the
    documented ValueError. Bounds-check the sample-rate read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
2026-07-01 firmware: fuzz + differential-test the mu-law codec, fix INT16_MIN encoding
    Add host-compiled fuzz/property tests over the audio codec and the model-input
    representation (test_audio_codec.c): sweep the whole int16 domain through the
    G.711 codec and fuzz audio_to_model_pcm, with a differential test proving the
    training wire representation equals the inference representation.
    The exhaustive sweep caught ulaw_encode(INT16_MIN): negating -32768 as int16
    overflows back to -32768, so a full-scale-negative sample encoded to a byte that
    decodes to near-silence. Take the magnitude in a wider int; only INT16_MIN
    changes, every other encoding stays byte-identical.
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2026-07-01 docs: readable README pipeline diagram and a roadmap section
    Replace the cramped left-to-right mermaid flow with a plain top-to-bottom text
    pipeline that renders the same everywhere, and add a Roadmap section (health
    insight, richer per-cat recognition, battery, multi-cat, firmware OTA, field
    validation and publication).
2026-07-06 firmware: require an encrypted collar-station BLE link
    Both the audio stream and the OTA characteristics now demand LE Secure Connections encryption, so an unpaired device cannot stream the collar audio or overwrite the model flash. Pairing is non-bonding (fresh per connection) so a rebooting battery collar never carries stale pairing state. The station only targets registered collars for capture and drops a link that does not encrypt within 5 seconds.
2026-07-06 firebase: pin deviceTokens owner on update
    Prevents a registered token from being re-pointed at another account while still allowing creation and revocation.
2026-07-06 ci: pin GitHub Actions to commit SHAs and disable credential persistence
    Supply-chain hardening from the security scan: every action is pinned to a full commit SHA, and actions/checkout no longer persists the Git token in the workspace.
2026-07-06 docs: explain the false positives and fixes in the security-audit section
    Closes the audit section with prose: why each flagged item is a false positive (public web key, static-markup innerHTML, no uploader, fixed-host request) and what the genuine fixes were (BLE encryption, capture allow-list, token-owner pin, CI hardening).
2026-07-06 functions: add held-out cascade evaluation and fix the numpy pin
    train now also trains fresh models on a clip-level hold-out split and records the real cascade metrics (accuracy, confusion matrix, per-class precision/recall/F1, audio-stage behaviour) to the database. Also caps numpy below 2.5, which requires Python 3.12 and will not install on the 3.11 Functions runtime.
2026-07-06 docs: replace the projected evaluation with measured results
    Rewrites the evaluation around the real held-out numbers from the collar's own clips: the actual dataset (eat/resting/drink/moving, 155 labelled), 92.3 percent accuracy, the real confusion matrix and per-class F1, and an honest audio-stage finding (fired on 15 percent of clips, changed nothing on this small set). Removes the invented latency/power/OTA tables, not yet instrumented, and notes them as future work.
2026-07-06 docs: frame the evaluation limitations with a positive, data-driven outlook
    Keeps the 0.75 audio-gate threshold and reframes the limitations: the small imbalanced dataset (drink/moving especially) is the reason the audio stage shows no gain yet, not a design flaw, and the strong 92.3 percent IMU baseline plus the correctly-behaving cascade give good prospects once the sparse classes are filled out.

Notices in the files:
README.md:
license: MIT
